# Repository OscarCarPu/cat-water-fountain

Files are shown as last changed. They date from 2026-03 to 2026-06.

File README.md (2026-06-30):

> ⚠️ **Project abandoned because there are no more cats.**

# cat-water-fountain
Automated drinking fountain for cats. Designed to activate a water pump when a cat is detected nearby and publish water level to an MQTT broker — currently in development.

More detailed docs in `docs/`:
- [Software](docs/software.md)
- [Hardware](docs/hardware.md)

## Tech stack

Bare-metal Rust on an ESP32 (Xtensa LX6), no operating system:

- `esp-hal` — hardware abstraction
- `esp-rtos` + `embassy-executor` — async runtime
- `embassy-net` + `esp-radio` — TCP/IP and WiFi
- `rust-mqtt` — MQTT v5 client

## Electronics

| Component | Part |
|---|---|
| Microcontroller | ESP32 (Xtensa LX6) |
| Cat sensor | HC-SR04 ultrasonic |
| Water level sensor | HC-SR04 ultrasonic |
| Pump | USB submersible 5V (TUNFAN PT-100cm, 150L/H) |
| Pump switch | IRLZ44N logic-level MOSFET |
| Flyback protection | 1N4001 diode across pump |
| Power | 3.2V LiFePO4 (MCU) + 5V power bank (pump and sensors) |

## Architecture

Designed around two concurrent embassy tasks plus a main loop:

1. **`detect_cat_task`** — polls the cat HC-SR04 every 100 ms and writes the result to a `static AtomicBool CAT_PRESENT`. Runs independently so motor reaction time stays around 100 ms regardless of the slower main cycle.
2. **`maintain_wifi_connection` / `run_network_stack`** — keeps the WiFi link and embassy-net stack alive; reconnects on disconnect. *(planned)*
3. **Main loop** (every 5 s) — reads water level (10-sample median-filtered HC-SR04), reads `CAT_PRESENT`, switches the motor on/off via MOSFET, publishes water level to MQTT. *(planned)*

## Configuration

Copy `eletronics/.env.example` to `eletronics/.env` and fill in:

| Variable | Purpose |
|---|---|
| `WIFI_SSID` | WiFi network name |
| `WIFI_PASSWORD` | WiFi password |
| `MQTT_SERVER` | Broker URL — must be `mqtt://<ipv4>:<port>` (hostnames not yet supported) |
| `MQTT_USER` | MQTT username |
| `MQTT_PASSWORD` | MQTT password |

Credentials are compiled into the firmware at build time via `build.rs`.

## GPIO pin assignment

| Function | Pin |
|---|---|
| Cat sensor — HC-SR04 trig | GPIO5 |
| Cat sensor — HC-SR04 echo | GPIO18 (via 1kΩ/2kΩ divider) |
| Water sensor — HC-SR04 trig | GPIO19 |
| Water sensor — HC-SR04 echo | GPIO21 (via 1kΩ/2kΩ divider) |
| Motor MOSFET gate | GPIO22 |

## Build & flash

```sh
make esp32-build-dev    # compile
make esp32-flash-dev    # compile, flash, and open serial monitor on /dev/ttyUSB0
make esp32-stop-dev     # erase flash
```

Requires the Espressif toolchain (`~/export-esp.sh`) and `espflash`.

## MQTT topics *(planned)*

| Topic | Direction | Payload | Cadence |
|---|---|---|---|
| `cat-water/water-level` | publish | filtered distance in cm, e.g. `"7.3"` | every 5 s |
| `cat-water/heartbeat` | publish | uptime or ping | every 5 s |

## Feature status

- [x] Hardware and system design
- [x] HC-SR04 distance reading
- [ ] HC-SR04 water level measurement
- [ ] Motor control via MOSFET
- [ ] MVP with just motor activated on cat detected
- [ ] ml-drank tracking
- [ ] MQTT water level publishing
- [ ] Heartbeat MQTT
- [ ] Telegram alerts (low-water / no heartbeat)
- [ ] Polishing details and structure

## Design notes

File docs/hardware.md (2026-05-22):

# Materials

## Container

Plastic container food safe:
- 21.8cm (length) * 15.8cm (width) * 13.8cm (height)
- On the top part it has some borders making it 24cm (length) * 18cm (width)
- https://www.aliexpress.com/item/1005010183592949.html

## Pump

USB Submersible Aquarium Pump (TUNFAN Store):
- Model: PT-100cm (adjustable flow, no filtration)
- Voltage: 5V
- Power: 5W
- Flow rate: 150L/H
- Max lift: 100cm
- Cable length: 50cm
- Outlet nozzle diameter: 8.4mm
- Size: 2.8cm x 3.8cm x 3.3cm
- Material: Rubber, copper motor
- Features: Adjustable flow, USB powered, submersible, suction cup base, mesh debris filter
- Price: ~3.85 EUR

## Tubing

PVC Transparent Water Tube:
- Size: 8mm inner diameter x 10mm outer diameter
- Length: 1 meter
- Material: PVC plastic
- Price: ~1.72 EUR

## Microcontroller

ESP32 (Xtensa LX6):
- Features: WiFi, Bluetooth
- Operating voltage: 3.3V
- TODO: add specific board link and detailed specs

## Sensors

### Ultrasonic Sensor - Cat Detection
- Model: HC-SR04 (or compatible)

### Ultrasonic Sensor - Water Level
- Model: HC-SR04 (or compatible)

## Power

### LiFePO4 Battery
- Voltage: 3.2V

### 5V Battery/Power Bank
- Requirements: 5V, 1A minimum (for pump and sensors)

## Electronic Components

### MOSFET
- Model: IRLZ44N (Logic Level MOSFET)
- Purpose: Pump switching control from ESP32

### Diode
- Model: 1N4001
- Purpose: Flyback protection, parallel to pump

### Capacitors
- 1000uF electrolytic - close to battery (power smoothing)
- 0.1uF ceramic - on motor terminals (noise filtering)

### Resistors
- 3kOhm x2 - Voltage divider for ultrasonic echo pins
- 2kOhm x2 - Voltage divider to GND for ultrasonic echo pins
- 1kOhm x2 - Voltage divider for ultrasonic echo pins
- 330Ohm x1 - MOSFET gate resistor
- 10kOhm x1 - MOSFET gate pull-down to GND

## 3D Printed Parts (PLA)

### Enclosure/Housing
- Purpose: Outer shell that encloses all components (container, pump, electronics)
- Material: PLA
- TODO: design and add STL files

## Other Materials

### Filtration
- Type: Active carbon or similar
- TODO: research and add specific product

### Ballast/Weight
- Purpose: Prevent container from tipping over
- TODO: determine material and specs

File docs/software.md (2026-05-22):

# Software

Written in bare metal Rust with:
- `esp-hal`: hardware abstraction
- `esp-rtos` + `embassy-executor`: async runtime
- `embassy-time`: async delays
- `embassy-net`: TCP/IP stack
- `esp-radio`: WiFi
- `rust-mqtt`: MQTT v5 client
- `esp-bootloader-esp-idf`: bootloader
- `esp-backtrace` / `esp-println`: panic handler + serial print

## Target

- `esp32` (Xtensa LX6): the only supported target. The previous `esp32c3` (XIAO/SuperMini) target has been removed.

Build/flash from the project root:
- `make esp32-build-dev` — compile
- `make esp32-flash-dev` — compile, flash, and open serial monitor on `/dev/ttyUSB0`
- `make esp32-stop-dev` — erase flash on the connected board

## Configuration

The firmware reads credentials at compile time from `eletronics/.env` (loaded by `build.rs`). Required keys:

| Variable | Purpose |
|---|---|
| `WIFI_SSID` | WiFi network name |
| `WIFI_PASSWORD` | WiFi network password |
| `MQTT_SERVER` | Broker URL — must be `mqtt://<ipv4>:<port>`, hostnames are not yet supported |
| `MQTT_USER` | MQTT username |
| `MQTT_PASSWORD` | MQTT password |

Copy `eletronics/.env.example` to `eletronics/.env` and fill it in before building.

## GPIO pin assignment

| Function | Pin |
|---|---|
| Cat sensor — HC-SR04 trig | GPIO5 |
| Cat sensor — HC-SR04 echo | GPIO18 (via 1kΩ/2kΩ divider) |
| Water sensor — HC-SR04 trig | GPIO19 |
| Water sensor — HC-SR04 echo | GPIO21 (via 1kΩ/2kΩ divider) |
| Motor MOSFET gate | GPIO22 |

## Architecture

Designed around two concurrent embassy tasks plus a main loop:

1. **`detect_cat_task`** — polls the cat HC-SR04 every 100 ms with a single measurement and writes the boolean result to a `static AtomicBool CAT_PRESENT`. Running it as its own task keeps motor reaction time around 100 ms, independent of the slower main cycle.
2. **`maintain_wifi_connection` / `run_network_stack`** — keep the WiFi link and embassy-net stack alive; reconnect on disconnect. *(planned)*
3. **`main` loop** (every 5 s) *(planned)*:
   - Read water level (10-sample median-filtered HC-SR04 read on the water sensor).
   - Read `CAT_PRESENT` and switch the motor on or off via MOSFET.
   - Publish the water level to MQTT.

## Motor control *(planned)*

The motor (USB submersible pump) will be gated by an IRLZ44N logic-level MOSFET driven from GPIO22.

- `Motor::on()` drives the gate high → pump runs.
- `Motor::off()` drives the gate low → 10kΩ gate pull-down keeps the MOSFET off.

The main loop will call `motor.on()` when `CAT_PRESENT` is true and `motor.off()` otherwise (fail-safe on sensor error). Detection threshold is `CAT_DETECTION_THRESHOLD_CM` in `main.rs`.

## MQTT topics *(planned)*

| Topic | Direction | Payload | Cadence |
|---|---|---|---|
| `cat-water/water-level` | publish | filtered distance in cm, formatted as `%.1f` (e.g. `"7.3"`) | every 5 s |
| `cat-water/heartbeat` | publish | uptime or ping | every 5 s |

The client will connect, publish, and disconnect each cycle; no persistent session.

## Feature status

- [x] Hardware and system design
- [x] HC-SR04 distance reading
- [ ] HC-SR04 water level measurement
- [ ] Motor control via MOSFET
- [ ] MVP with just motor activated on cat detected
- [ ] ml-drank tracking
- [ ] MQTT water level publishing
- [ ] Heartbeat MQTT
- [ ] Telegram alerts (low-water / no heartbeat)
- [ ] Polishing details and structure

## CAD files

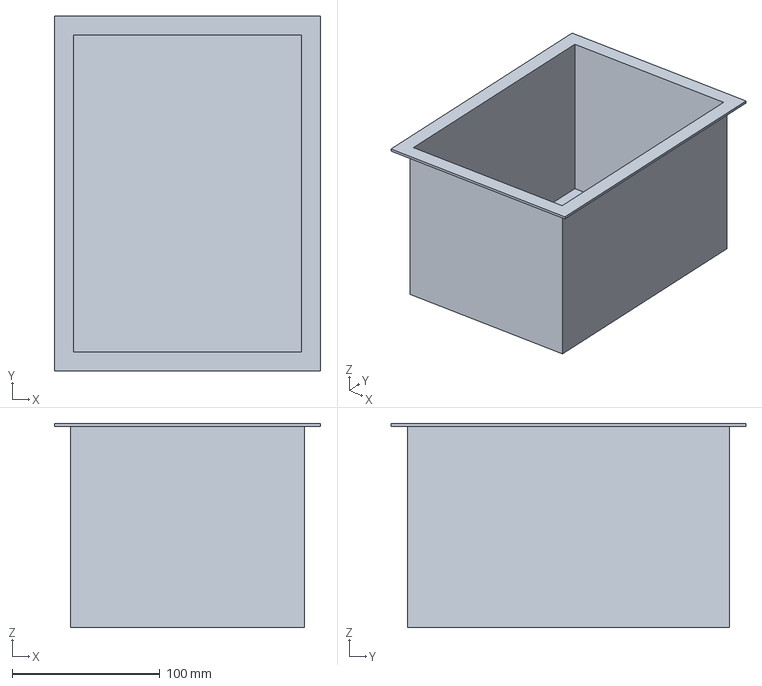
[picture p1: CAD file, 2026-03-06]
hardware/PLA model.FCStd
180.0 x 240.0 x 138.0 mm

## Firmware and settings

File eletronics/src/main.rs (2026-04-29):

#![no_std]
#![no_main]

extern crate alloc;

use core::sync::atomic::{AtomicBool, Ordering};

use embassy_executor::Spawner;
use embassy_net::{Runner, Stack, StackResources, tcp::TcpSocket};
use embassy_time::{Instant, Timer};
use esp_alloc as _;
use esp_backtrace as _;
use esp_hal::{
    clock::CpuClock,
    gpio::{Input, InputConfig, Level, Output, OutputConfig, Pull},
    rng::Rng,
    timer::timg::TimerGroup,
};
use esp_println::println;
use esp_radio::{
    Controller,
    wifi::{ClientConfig, ModeConfig, WifiController, WifiDevice, WifiEvent, WifiStaState},
};
use rust_mqtt::{
    Bytes,
    buffer::AllocBuffer,
    client::{
        Client,
        options::{ConnectOptions, PublicationOptions},
    },
    config::{KeepAlive, SessionExpiryInterval},
    types::{MqttBinary, MqttString, QoS, TopicName},
};

esp_bootloader_esp_idf::esp_app_desc!();

macro_rules! mk_static {
    ($t:ty,$val:expr) => {{
        static STATIC_CELL: static_cell::StaticCell<$t> = static_cell::StaticCell::new();
        #[deny(unused_attributes)]
        let x = STATIC_CELL.uninit().write(($val));
        x
    }};
}

const WIFI_SSID: &str = env!("WIFI_SSID");
const WIFI_PASSWORD: &str = env!("WIFI_PASSWORD");
const MQTT_SERVER: &str = env!("MQTT_SERVER");
const MQTT_USER: &str = env!("MQTT_USER");
const MQTT_PASSWORD: &str = env!("MQTT_PASSWORD");

const HC_SR04_TIMEOUT_US: u64 = 30_000;
const HC_SR04_SAMPLES: usize = 10;
const HC_SR04_TRIM: usize = HC_SR04_SAMPLES / 5;

const CAT_DETECTION_THRESHOLD_CM: f32 = 25.0;
const CAT_POLL_INTERVAL_MS: u64 = 100;
const MAIN_LOOP_INTERVAL_MS: u64 = 5_000;

static CAT_PRESENT: AtomicBool = AtomicBool::new(false);

#[esp_rtos::main]
async fn main(spawner: Spawner) -> ! {
    let peripherals = esp_hal::init(esp_hal::Config::default().with_cpu_clock(CpuClock::max()));
    esp_alloc::heap_allocator!(size: 72 * 1024);

    let timg0 = TimerGroup::new(peripherals.TIMG0);
    esp_rtos::start(timg0.timer0);

    let cat_sensor = HcSr04::new(
        Output::new(peripherals.GPIO5, Level::Low, OutputConfig::default()),
        Input::new(
            peripherals.GPIO18,
            InputConfig::default().with_pull(Pull::Down),
        ),
    );
    let mut water_sensor = HcSr04::new(
        Output::new(peripherals.GPIO19, Level::Low, OutputConfig::default()),
        Input::new(
            peripherals.GPIO21,
            InputConfig::default().with_pull(Pull::Down),
        ),
    );
    let mut motor = Motor::new(Output::new(
        peripherals.GPIO22,
        Level::Low,
        OutputConfig::default(),
    ));

    let mqtt = mk_static!(MqttResources, MqttResources::new());

    let stack = setup_wifi_stack(&spawner, peripherals.WIFI).await;
    wait_for_wifi_ready(stack).await;

    spawner.spawn(detect_cat_task(cat_sensor)).ok();

    println!("--- Cat Water Fountain ---");

    loop {
        let water_level_cm = read_water_level_cm(&mut water_sensor).await;
        println!("Water level: {:?} cm", water_level_cm);

        if CAT_PRESENT.load(Ordering::Relaxed) {
            motor.on();
        } else {
            motor.off();
        }

        publish_water_level(stack, water_level_cm, mqtt).await;

        Timer::after_millis(MAIN_LOOP_INTERVAL_MS).await;
    }
}

// ============================================================
// HC-SR04 driver
// ============================================================

struct HcSr04<'a> {
    trig: Output<'a>,
    echo: Input<'a>,
}

impl<'a> HcSr04<'a> {
    fn new(trig: Output<'a>, echo: Input<'a>) -> Self {
        Self { trig, echo }
    }

    async fn take_single_measurement_cm(&mut self) -> Option<f32> {
        use esp_hal::delay::Delay;

        let delay = Delay::new();
        self.trig.set_high();
        delay.delay_micros(10);
        self.trig.set_low();

        let timeout = Instant::now();
        while self.echo.is_low() {
            if Instant::now().duration_since(timeout).as_micros() > HC_SR04_TIMEOUT_US {
                return None;
            }
        }

        let echo_start = Instant::now();
        while self.echo.is_high() {
            if Instant::now().duration_since(echo_start).as_micros() > HC_SR04_TIMEOUT_US {
                return None;
            }
        }

        let pulse_us = Instant::now().duration_since(echo_start).as_micros();
        Some(pulse_us as f32 / 58.0)
    }

    async fn read_filtered_distance_cm(&mut self) -> Option<f32> {
        let mut samples = [0.0f32; HC_SR04_SAMPLES];
        let mut collected = 0usize;
        while collected < HC_SR04_SAMPLES {
            if let Some(cm) = self.take_single_measurement_cm().await {
                samples[collected] = cm;
                collected += 1;
            }
            Timer::after_millis(500).await;
        }
        Some(clean_distance_samples(&samples))
    }
}

fn clean_distance_samples(samples: &[f32; HC_SR04_SAMPLES]) -> f32 {
    let mut sorted = *samples;
    for i in 1..sorted.len() {
        let mut j = i;
        while j > 0 && sorted[j - 1] > sorted[j] {
            sorted.swap(j - 1, j);
            j -= 1;
        }
    }
    let middle = &sorted[HC_SR04_TRIM..HC_SR04_SAMPLES - HC_SR04_TRIM];
    let sum: f32 = middle.iter().sum();
    sum / middle.len() as f32
}

// ============================================================
// Cat sensor
// ============================================================

async fn read_cat_distance_cm(sensor: &mut HcSr04<'_>) -> Option<f32> {
    sensor.take_single_measurement_cm().await
}

#[embassy_executor::task]
async fn detect_cat_task(mut sensor: HcSr04<'static>) {
    loop {
        if let Some(cm) = read_cat_distance_cm(&mut sensor).await {
            CAT_PRESENT.store(cm < CAT_DETECTION_THRESHOLD_CM, Ordering::Relaxed);
        }
        Timer::after_millis(CAT_POLL_INTERVAL_MS).await;
    }
}

// ============================================================
// Water sensor
// ============================================================

async fn read_water_level_cm(sensor: &mut HcSr04<'_>) -> Option<f32> {
    sensor.read_filtered_distance_cm().await
}

// ============================================================
// Motor
// ============================================================

struct Motor<'a> {
    gate: Output<'a>,
}

impl<'a> Motor<'a> {
    fn new(gate: Output<'a>) -> Self {
        Self { gate }
    }

    fn on(&mut self) {
        self.gate.set_high();
        println!("Motor on");
    }

    fn off(&mut self) {
        self.gate.set_low();
        println!("Motor off");
    }
}

// ============================================================
// WiFi
// ============================================================

async fn setup_wifi_stack(
    spawner: &Spawner,
    wifi: esp_hal::peripherals::WIFI<'static>,
) -> Stack<'static> {
    let esp_radio_ctrl = &*mk_static!(Controller<'static>, esp_radio::init().unwrap());
    let (controller, interfaces) =
        esp_radio::wifi::new(esp_radio_ctrl, wifi, Default::default()).unwrap();
    let device = interfaces.sta;

    let net_config = embassy_net::Config::dhcpv4(Default::default());

    let rng = Rng::new();
    let seed = (rng.random() as u64) << 32 | rng.random() as u64;

    let (stack, runner) = embassy_net::new(
        device,
        net_config,
        mk_static!(StackResources<3>, StackResources::<3>::new()),
        seed,
    );

    Timer::after_millis(2000).await;
    spawner.spawn(maintain_wifi_connection(controller)).ok();
    spawner.spawn(run_network_stack(runner)).ok();

    stack
}

async fn wait_for_wifi_ready(stack: Stack<'static>) {
    while !stack.is_link_up() {
        Timer::after_millis(500).await;
    }
    while !stack.is_config_up() {
        Timer::after_millis(100).await;
    }
    stack
        .config_v4()
        .inspect(|c| println!("IPv4 config: {c:?}"));
}

#[embassy_executor::task]
async fn maintain_wifi_connection(mut controller: WifiController<'static>) {
    println!("Device capabilities: {:?}", controller.capabilities());
    loop {
        match esp_radio::wifi::sta_state() {
            WifiStaState::Connected => {
                controller.wait_for_event(WifiEvent::StaDisconnected).await;
                Timer::after_millis(5000).await;
            }
            _ => {}
        }

        if !matches!(controller.is_started(), Ok(true)) {
            let client_config = ModeConfig::Client(
                ClientConfig::default()
                    .with_ssid(WIFI_SSID.try_into().unwrap())
                    .with_password(WIFI_PASSWORD.try_into().unwrap()),
            );
            controller.set_config(&client_config).unwrap();
            println!("Starting WiFi...");
            controller.start_async().await.unwrap();
            println!("WiFi started!");
            controller
                .set_power_saving(esp_radio::wifi::PowerSaveMode::Maximum)
                .unwrap();
        }

        println!("Connecting to '{}'...", WIFI_SSID);
        match controller.connect_async().await {
            Ok(_) => println!("WiFi connected!"),
            Err(e) => {
                println!("WiFi connect failed: {:?}", e);
                Timer::after_millis(5000).await;
            }
        }
    }
}

#[embassy_executor::task]
async fn run_network_stack(mut runner: Runner<'static, WifiDevice<'static>>) {
    runner.run().await
}

// ============================================================
// MQTT
// ============================================================

struct MqttResources {
    client_buffer: AllocBuffer,
    rx_buf: [u8; 4096],
    tx_buf: [u8; 4096],
}

impl MqttResources {
    fn new() -> Self {
        Self {
            client_buffer: AllocBuffer,
            rx_buf: [0u8; 4096],
            tx_buf: [0u8; 4096],
        }
    }
}

async fn publish_water_level(
    stack: Stack<'static>,
    water_level_cm: Option<f32>,
    mqtt: &mut MqttResources,
) {
    let Some(cm) = water_level_cm else {
        return;
    };

    let host_port = MQTT_SERVER.strip_prefix("mqtt://").unwrap_or(MQTT_SERVER);
    let (host, port) = host_port.rsplit_once(':').unwrap_or((host_port, "1883"));
    let remote_ip: embassy_net::Ipv4Address = host.parse().unwrap();
    let remote_port: u16 = port.parse().unwrap();

    let mut socket = TcpSocket::new(stack, &mut mqtt.rx_buf, &mut mqtt.tx_buf);
    socket.set_timeout(Some(embassy_time::Duration::from_secs(10)));
    if let Err(e) = socket.connect((remote_ip, remote_port)).await {
        println!("MQTT TCP connect failed: {:?}", e);
        return;
    }

    let connect_options = ConnectOptions {
        clean_start: true,
        keep_alive: KeepAlive::default(),
        session_expiry_interval: SessionExpiryInterval::NeverEnd,
        user_name: Some(MqttString::from_slice(MQTT_USER).unwrap()),
        password: Some(MqttBinary::from_slice(MQTT_PASSWORD.as_bytes()).unwrap()),
        will: None,
    };
    let mut client = Client::<'_, _, _, 1, 1, 1>::new(&mut mqtt.client_buffer);
    if let Err(e) = client
        .connect(
            socket,
            &connect_options,
            Some(MqttString::from_slice("cat-water-fountain").unwrap()),
        )
        .await
    {
        println!("MQTT CONNECT failed: {:?}", e);
        return;
    }

    let mut buf = [0u8; 16];
    let len = format_decimal(&mut buf, cm);
    let topic =
        unsafe { TopicName::new_unchecked(MqttString::from_slice("cat-water/water-level").unwrap()) };
    let opts = PublicationOptions {
        retain: false,
        topic: topic.as_borrowed(),
        qos: QoS::AtMostOnce,
    };
    if let Err(e) = client.publish(&opts, Bytes::Borrowed(&buf[..len])).await {
        println!("MQTT publish failed: {:?}", e);
    }
}

fn format_decimal(buf: &mut [u8], value: f32) -> usize {
    use core::fmt::Write;
    struct W<'b> {
        buf: &'b mut [u8],
        pos: usize,
    }
    impl core::fmt::Write for W<'_> {
        fn write_str(&mut self, s: &str) -> core::fmt::Result {
            let bytes = s.as_bytes();
            let end = self.pos + bytes.len();
            if end > self.buf.len() {
                return Err(core::fmt::Error);
            }
            self.buf[self.pos..end].copy_from_slice(bytes);
            self.pos = end;
            Ok(())
        }
    }
    let mut w = W { buf, pos: 0 };
    let _ = write!(w, "{:.1}", value);
    w.pos
}

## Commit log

2026-03-03 feat: add initial electronics and software implementation for cat drinking fountain
    * Add .gitignore file to ignore target and Cargo.lock files
    * Update README.md to include link to software documentation
    * Create initial software documentation in docs/software.md
    * Create initial electronics implementation in eletronics directory
    * Add build.rs file to configure linker and handle undefined symbols
    * Add Cargo.toml file to define electronics package and dependencies
    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
2026-03-06 feat: add hardware documentation and 3D model files
    * Create new documentation for hardware components in docs/hardware.md
    * Add 3D model files for PLA enclosure in hardware/ directory
    * Update README.md to include link to hardware documentation and describe hardware components
    [PLA model.FCStd]
2026-03-20 feat: add WiFi and MQTT connectivity to the cat water fountain project
    - feat: add WiFi support using embassy-net
    - feat: add MQTT support using rust-mqtt
    - feat: implement sensor reading and water level publishing to MQTT
    - feat: add ping sending to MQTT on startup
    - refactor: update main function to use embassy-executor and async/await
    - refactor: extract mqtt_task and sensor_read functions for better readability and maintainability
2026-04-29 refactor: remove WiFi and MQTT, consolidate to ESP32-only, add Makefile
2026-04-29 feat: implement WiFi, MQTT messaging, and motor control
2026-05-22 docs: overhaul README and sync docs with current implementation state
